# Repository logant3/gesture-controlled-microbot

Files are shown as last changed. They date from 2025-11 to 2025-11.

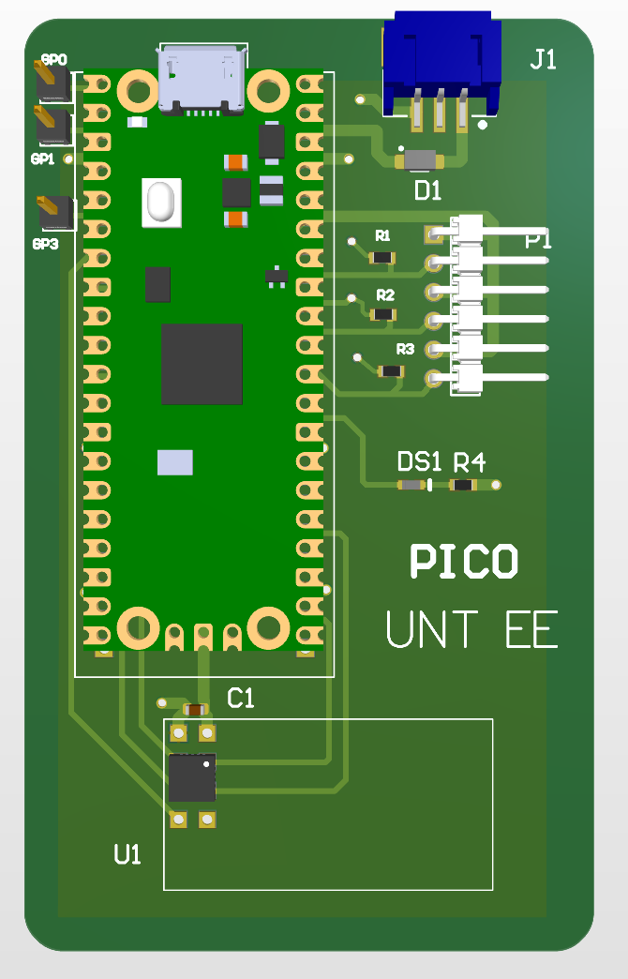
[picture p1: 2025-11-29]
hardware/pcb_layout/screenshots/TX_3D_View.png

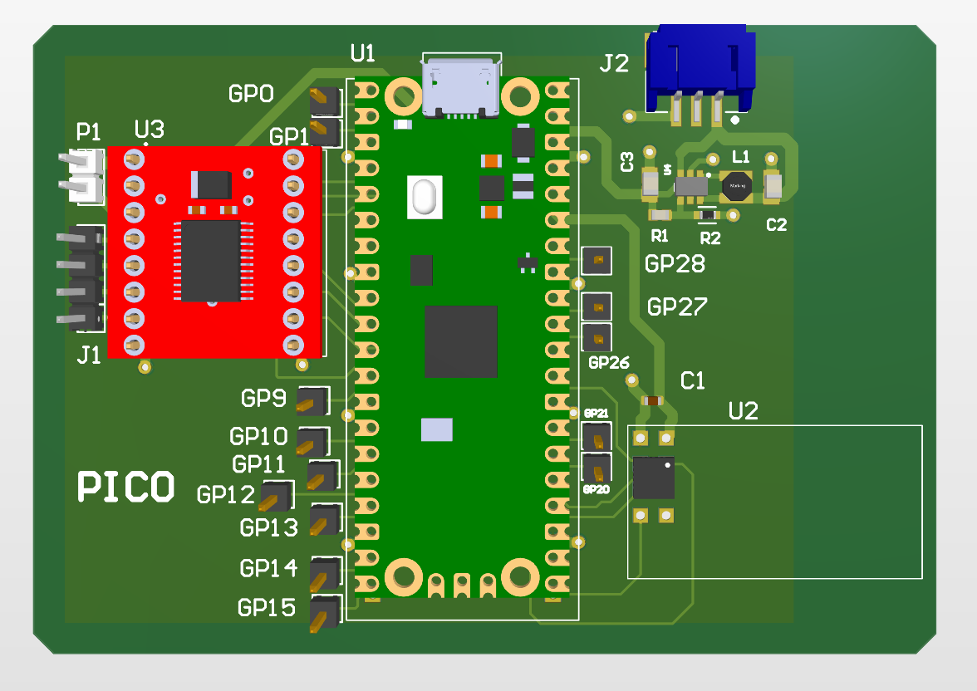
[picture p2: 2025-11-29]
hardware/pcb_layout/screenshots/RX_3D_View.png

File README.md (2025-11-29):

# Gesture-Controlled-Microbot
A full custom-PCB system for wireless, gesture-based robot control. Includes Pico-powered flex-sensor glove (TX), NRF24L01 RF link, and a robot module with TB6612FNG motor driver, boost regulation, and SPI OLED eye animations. Demonstrates hardware, firmware, and system design.

main_microbot

# Features
* Custom-designed PCBs for both TX (glove) and RX (robot)

* Real-time gesture control using three flex sensors mapped to Left / Forward / Right

* Reliable 2.4 GHz wireless communication with NRF24L01+

* Raspberry Pi Pico on both modules (SPI + ADC + PWM control)

* Dual-power system with LiPo + boost regulation

* TB6612FNG motor driver powering two DC motors with PWM speed control

* Two SH1106 SPI OLED displays rendering wandering animated eyes

* Modular and readable MicroPython codebase

# How it Works
**Hand Module (TX)**

The glove uses three flex sensors wired in voltage dividers and read through the Pico’s ADC pins.
Each sensor bend is converted into a 3-bit command mask:

| Gesture | Bitmask | Decimal |
| :--- | :---: | ---: |
| Stop | 000 | 0 |
| Left | 001 | 1 |
| Forward | 010 | 2 |
| Right | 100 | 4 |

This value is transmitted over the NRF24L01+ radio every 50 ms.

**Robot Module (RX)**

The receiving Pico decodes the bitmask and drives a TB6612FNG motor driver using PWM signals.
A separate 6V pack powers the motors, while a 3.7V LiPo → 5V boost converter powers logic.
Two SPI OLED displays render expressive “robot eyes” using lightweight non-blocking animations.

The robot moves immediately upon receiving a valid packet, but continues animating the eyes whenever idle.

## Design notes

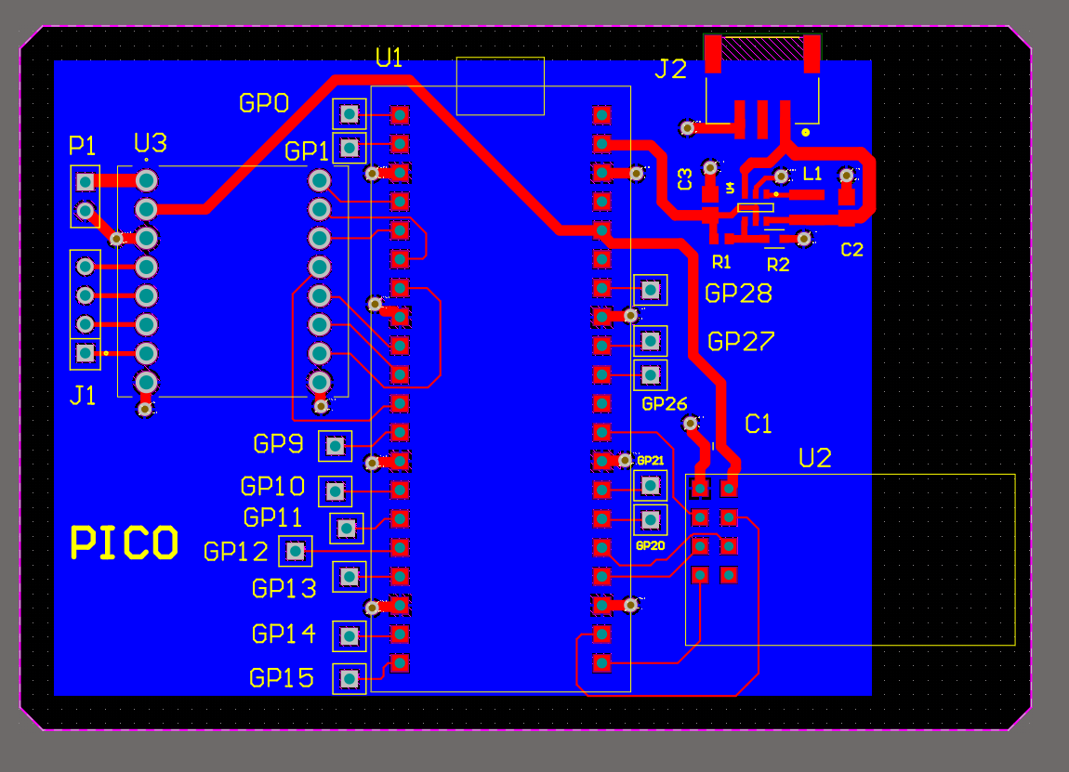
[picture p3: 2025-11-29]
hardware/pcb_layout/screenshots/RX_2D_View.png

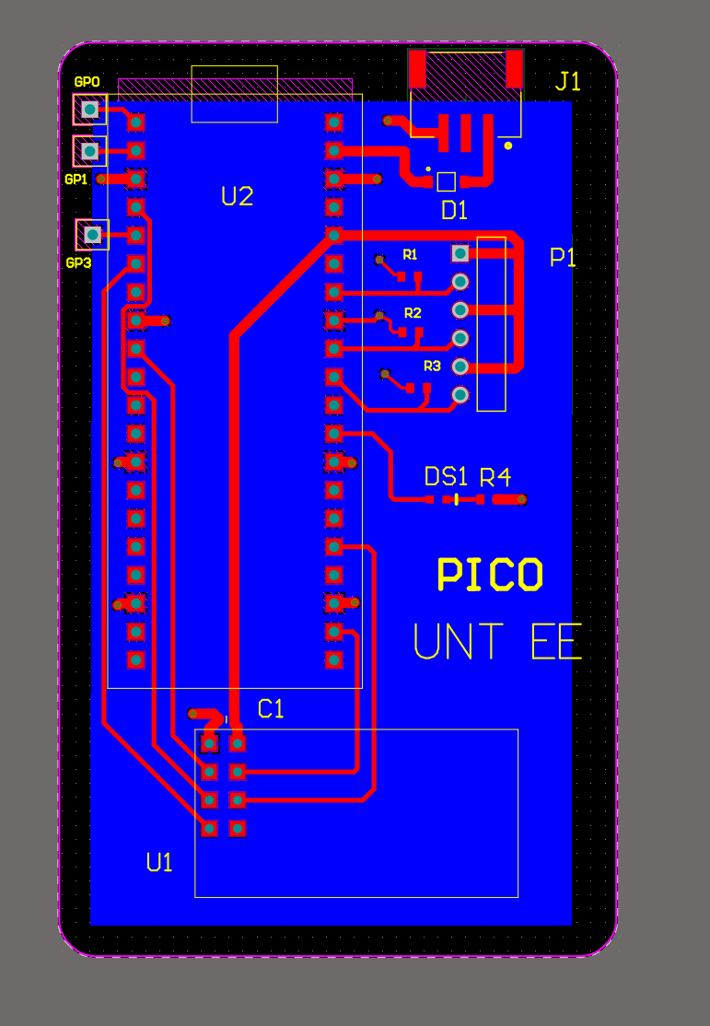
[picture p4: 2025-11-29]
hardware/pcb_layout/screenshots/TX_2D_View.png

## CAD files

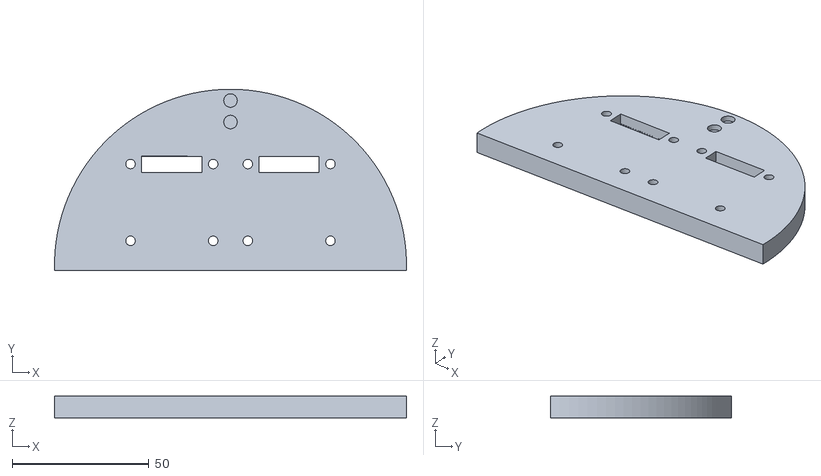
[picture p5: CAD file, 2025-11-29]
hardware/3D_print_files/BackFace.stl
128.8 x 66.4 x 7.98

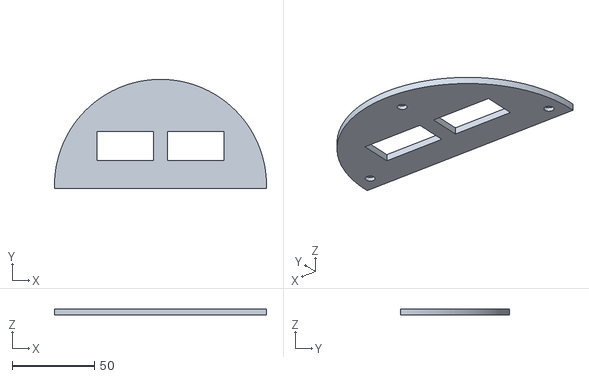
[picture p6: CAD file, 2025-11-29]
hardware/3D_print_files/FrontFace.stl
128.8 x 66.4 x 3.50

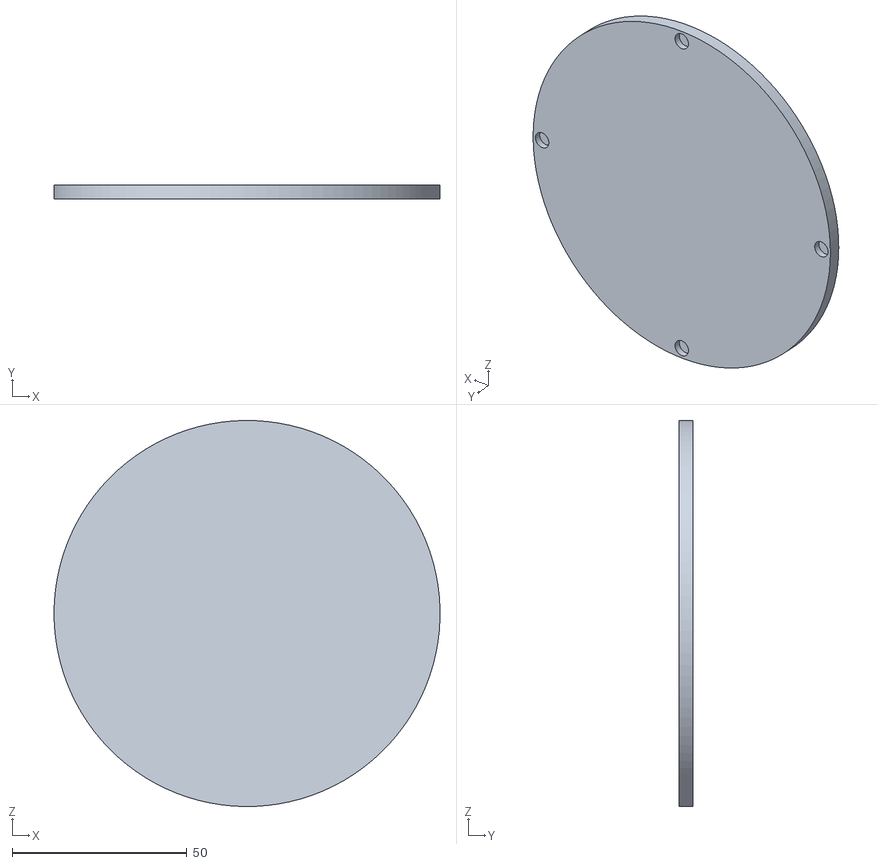
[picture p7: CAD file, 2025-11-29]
hardware/3D_print_files/Lid.stl
110.4 x 4.00 x 110.4

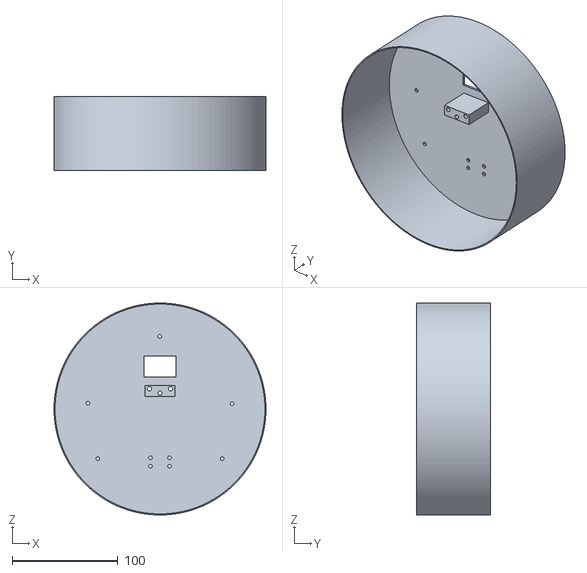
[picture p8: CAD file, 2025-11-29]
hardware/3D_print_files/Skirt.stl
200.0 x 70.0 x 200.0

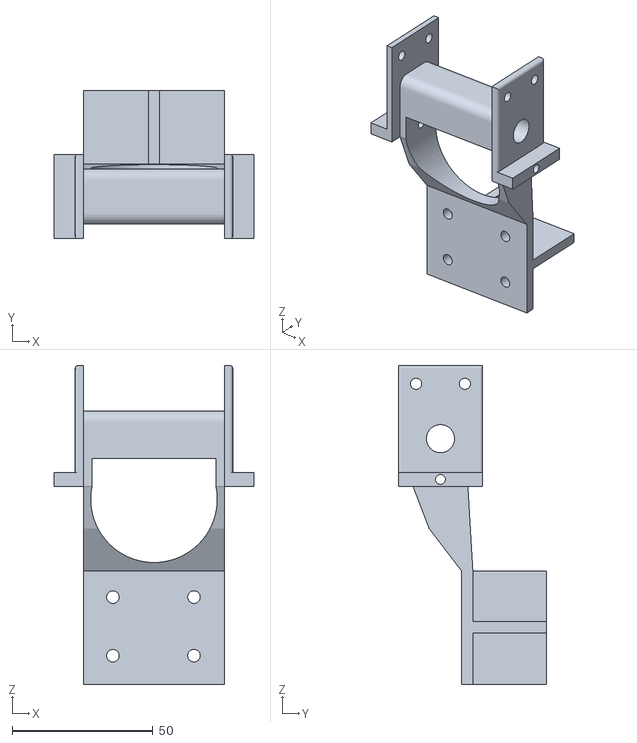
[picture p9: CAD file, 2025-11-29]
hardware/3D_print_files/WheelMount.stl
71.0 x 52.8 x 113.3

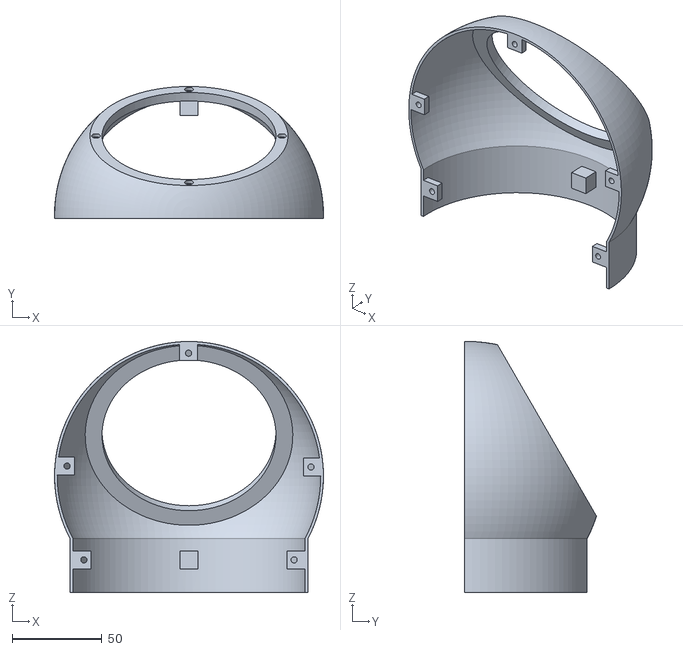
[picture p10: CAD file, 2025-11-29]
hardware/3D_print_files/Head.stl
150.0 x 73.6 x 140.0

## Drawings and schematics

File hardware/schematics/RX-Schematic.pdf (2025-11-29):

# GND²

# TSW-102-26-T-S 6V

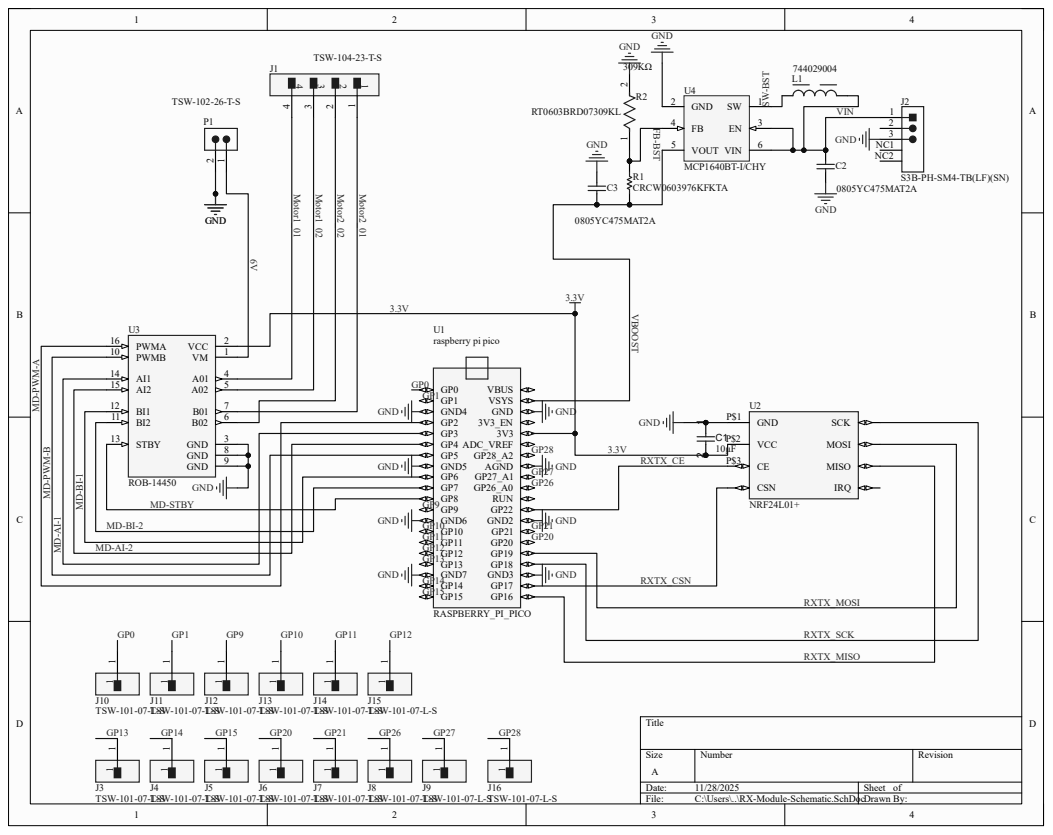
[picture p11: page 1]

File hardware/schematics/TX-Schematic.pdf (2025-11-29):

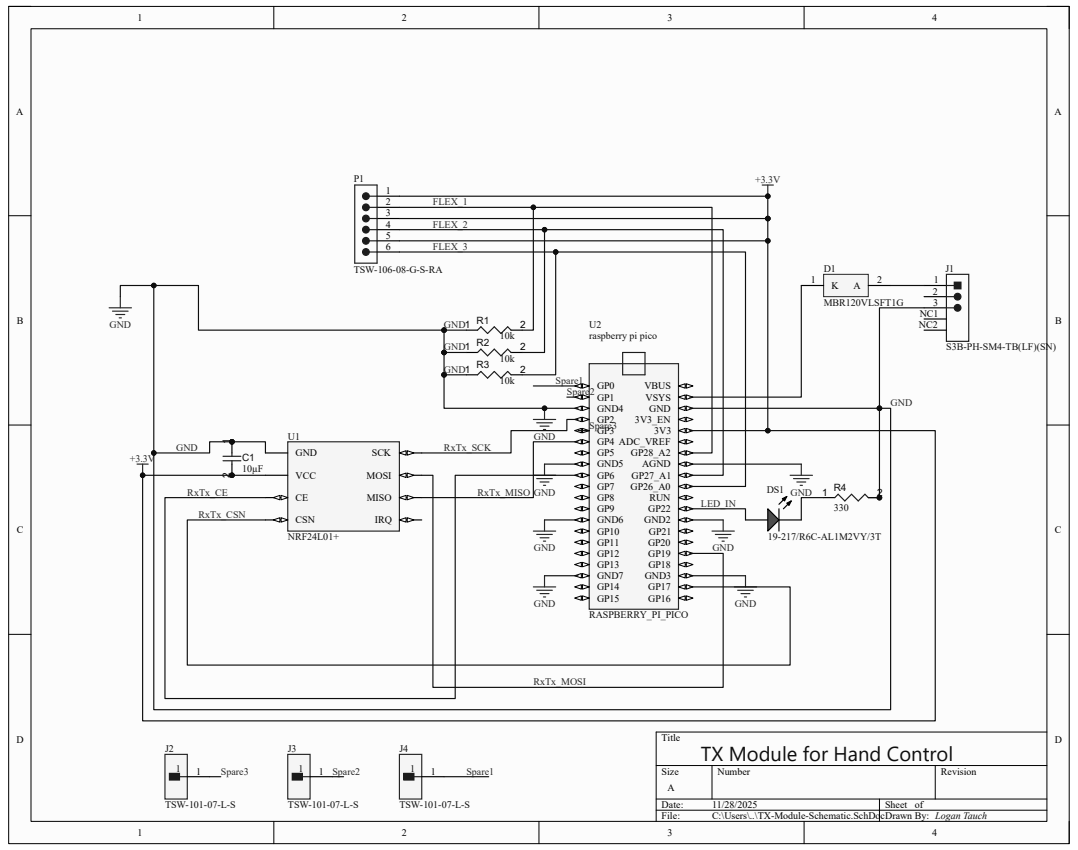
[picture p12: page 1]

Title
TX Module for Hand Control

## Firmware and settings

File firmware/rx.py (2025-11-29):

from machine import Pin, PWM, SPI
from nrf24l01 import NRF24L01
from sh1106 import SH1106_SPI
from roboeyes import RoboEyes
import time, urandom, math


#   Setting eyes up on SPI1

spi1 = SPI(1, baudrate=9000000, polarity=0, phase=0,
           sck=Pin(14), mosi=Pin(15))

# Left screen pin assignments
dcL  = Pin(12, Pin.OUT)
rstL = Pin(13, Pin.OUT)
csL  = Pin(9, Pin.OUT)
oledL = SH1106_SPI(128, 64, spi1, dcL, rstL, csL)

# Right screen pin assignments
dcR  = Pin(21, Pin.OUT)
rstR = Pin(26, Pin.OUT)
csR  = Pin(20, Pin.OUT)
oledR = SH1106_SPI(128, 64, spi1, dcR, rstR, csR)

oledL.fill(0); oledL.show()
oledR.fill(0); oledR.show()

# Safe show callbacks

def show_left(re):
    oledL.show()

def show_right(re):
    oledR.show()



# Define eyes

leftEye  = RoboEyes(oledL, 128, 64, frame_rate=30, on_show=show_left)
rightEye = RoboEyes(oledR, 128, 64, frame_rate=30, on_show=show_right)

leftEye.cyclops  = True
rightEye.cyclops = True


# Define eyes dimensions

EYE_W = 50    # eye width
EYE_H = 50    # eye height
EYE_R = 25    # eye radius

leftEye.eyes_width(EYE_W, EYE_W)
rightEye.eyes_width(EYE_W, EYE_W)

leftEye.eyes_height(EYE_H, EYE_H)
rightEye.eyes_height(EYE_H, EYE_H)

leftEye.eyes_radius(EYE_R, EYE_R)
rightEye.eyes_radius(EYE_R, EYE_R)
 
# Center the eyes on the OLED screens
def center_eye(re):
    re.eyeLx = re.eyeLxNext = (128 - EYE_W)//2 + 3
    re.eyeLy = re.eyeLyNext = (64  - EYE_H)//2

center_eye(leftEye)
center_eye(rightEye)



SAFE_MARGIN = 4   # keep all eye movements within 4 pixels on top and bottom

def apply_vertical_clamp(re):
    # Keep left eye within safe margin zones
    if re.eyeLy < SAFE_MARGIN:
        re.eyeLy = SAFE_MARGIN
    if re.eyeLy + re.eyeLheightCurrent > (64 - SAFE_MARGIN):
        re.eyeLy = 64 - SAFE_MARGIN - re.eyeLheightCurrent

    # Keep right eye within safe margin zones
    if re.eyeRy < SAFE_MARGIN:
        re.eyeRy = SAFE_MARGIN
    if re.eyeRy + re.eyeRheightCurrent > (64 - SAFE_MARGIN):
        re.eyeRy = 64 - SAFE_MARGIN - re.eyeRheightCurrent


# override roboeyes so we can include the vertical safety clamp after roboeyes runs
_original_update = RoboEyes.update

def safe_update(self):
    _original_update(self)
    apply_vertical_clamp(self)

RoboEyes.update = safe_update



# Blink and idle declarations

leftEye.set_idle_mode(True, interval=2, variation=2)
rightEye.set_idle_mode(True, interval=2, variation=2)

leftEye.set_auto_blinker(True, interval=2, variation=3)
rightEye.set_auto_blinker(True, interval=2, variation=3)

leftEye.mood = 4 #happy mood
rightEye.mood = 4




FORWARD_SPEED = 35000 # motor speed for forward
TURN_SPEED = 18000 #motor speed for turns

# Motor driver pin assignments

AIN1 = Pin(3, Pin.OUT)
AIN2 = Pin(4, Pin.OUT)
BIN1 = Pin(6, Pin.OUT)
BIN2 = Pin(7, Pin.OUT)

PWMA = PWM(Pin(2)); PWMA.freq(1000)
PWMB = PWM(Pin(5)); PWMB.freq(1000)

STBY = Pin(8, Pin.OUT); STBY.value(1)

#transciever pin assignments and setup

spi0 = SPI(0, baudrate=4000000, polarity=0, phase=0,
           sck=Pin(18), mosi=Pin(19), miso=Pin(16))

csn = Pin(17, Pin.OUT, value=1)
ce  = Pin(22, Pin.OUT, value=0)

nrf = NRF24L01(spi0, csn, ce, channel=76, payload_size=1)
nrf.open_rx_pipe(0, b"BOT01")
nrf.start_listening()


#definitions for moving functions


def stop():
    AIN1.value(0); AIN2.value(0)
    BIN1.value(0); BIN2.value(0)
    PWMA.duty_u16(0)
    PWMB.duty_u16(0)

def forward():
    AIN1.value(1); AIN2.value(0)
    BIN1.value(1); BIN2.value(0)
    PWMA.duty_u16(FORWARD_SPEED)
    PWMB.duty_u16(FORWARD_SPEED)

def left():
    AIN1.value(0); AIN2.value(1)
    BIN1.value(1); BIN2.value(0)
    PWMA.duty_u16(TURN_SPEED)
    PWMB.duty_u16(TURN_SPEED)

def right():
    AIN1.value(1); AIN2.value(0)
    BIN1.value(0); BIN2.value(1)
    PWMA.duty_u16(TURN_SPEED)
    PWMB.duty_u16(TURN_SPEED)



while True:
    if nrf.any():
        mask = nrf.recv()[0]

        left_cmd    = bool(mask & 0b001)
        forward_cmd = bool(mask & 0b010)
        right_cmd   = bool(mask & 0b100)

        if forward_cmd:
            forward()
            leftEye.mood = 4
            rightEye.mood = 4
        elif left_cmd:
            left()
        elif right_cmd:
            right()
        else:
            stop()
            leftEye.mood = 2
            rightEye.mood = 2

    leftEye.update()
    rightEye.update()

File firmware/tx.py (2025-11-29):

from machine import Pin, SPI, ADC
from nrf24l01 import NRF24L01
import time, struct


# Flex sensor assignments
flex_left    = ADC(26)   # ADC0
flex_forward = ADC(27)   # ADC1
flex_right   = ADC(28)   # ADC2

# test LED
led = Pin(22, Pin.OUT)


# NRF24L01 on SPI0 pin assignments

spi = SPI(
    0,
    baudrate=4000000,
    polarity=0,
    phase=0,
    sck=Pin(2),      # SPI0 SCK
    mosi=Pin(19),    # SPI0 MOSI
    miso=Pin(4)      # SPI0 MISO
)

csn = Pin(17, Pin.OUT, value=1)   # CSN
ce  = Pin(6,  Pin.OUT, value=0)   # CE

ADDRESS = b"BOT01"
CHANNEL = 76
PAYLOAD = 1

radio = NRF24L01(spi, csn, ce, channel=CHANNEL, payload_size=PAYLOAD)
radio.open_tx_pipe(ADDRESS)

print("TX READY")

# BUILD CONTROL MASK

def read_mask():
    left_raw    = flex_left.read_u16()
    forward_raw = flex_forward.read_u16()
    right_raw   = flex_right.read_u16()

    # threshold values for 
    left     = 1 if left_raw    < 22000 else 0
    forward  = 1 if forward_raw < 22000 else 0
    right    = 1 if right_raw   < 22000 else 0

    mask = (left << 0) | (forward << 1) | (right << 2)

    return mask


while True:
    mask = read_mask()
    packet = struct.pack("B", mask)

    # LED on when commands are sent
    led.value(1 if mask != 0 else 0)

    try:
        radio.send(packet)
        print("Sent mask:", mask)
    except OSError as e:
        print("TX error:", e)

    time.sleep(0.03)

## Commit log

2025-11-29 Create schematics
2025-11-29 Create pcb_layout
